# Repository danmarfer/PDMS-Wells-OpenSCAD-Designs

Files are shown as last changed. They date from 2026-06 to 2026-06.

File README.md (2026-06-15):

# PDMS Well Mold Designs — OpenSCAD Parametric Models

Parametric 3D-printable mold designs for casting **PDMS (Polydimethylsiloxane) wells** used in cell biology, microfluidics, and lab-on-a-chip experiments. All files are built in [OpenSCAD](https://openscad.org/) so that any dimension can be changed by editing a single variable — no CAD experience needed.

---

## Who Is This For?

Researchers who need custom PDMS chambers for cell biology, microfluidics, or live-cell imaging experiments, but do not have CAD design experience. All dimensions are exposed as plain variables at the top of each file — adapting a design to your experiment requires no knowledge of 3D modeling.

> A detailed design flow describing the full fabrication workflow is currently under review for publication. This section will be updated with the reference once available.

---

## Repository Contents

| File | Description |
| --- | --- |
| `Well.scad` | The final PDMS well — the part you cast |
| `Lid.scad` | Snap-fit lid with alignment pegs for the well |
| `One part mold.scad` | **(Design A)** Simplest mold — single piece, print-and-use |
| `Removable gate mold.scad` | **(Design B)** Two-part mold with a sliding gate insert |
| `Removable base mold.scad` | **(Design C)** Two-part mold with a removable base peg |
| `Removable cylinder mold.scad` | **(Design D)** Scaled-up two-part mold with a large removable cylinder |

---

## Mold Designs

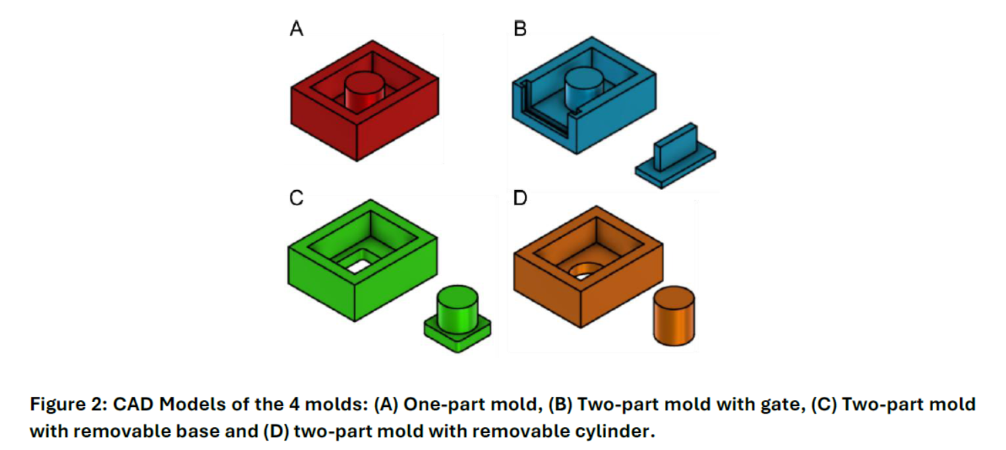
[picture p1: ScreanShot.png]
CAD Models of the 4 molds: (A) One-part mold, (B) Two-part mold with gate, (C) Two-part mold with removable base and (D) two-part mold with removable cylinder.


*Figure: CAD Models of the 4 molds — (A) One-part mold, (B) Two-part mold with gate, (C) Two-part mold with removable base, (D) Two-part mold with removable cylinder.*

---

### A — One-Part Mold (`One part mold.scad`)

The simplest design. The entire mold is a single printed piece. The cylindrical post that forms the well opening is part of the body — nothing to assemble before pouring.

**Default dimensions:**
- Inner cavity: 20 × 15 × 7 mm
- Well hole diameter: 7 mm
- Wall thickness: 2 mm

**Demolding:** Flex the mold walls outward and pull the cured PDMS straight up. Because the cylinder is built-in, this requires more force than the two-part options.

---

### B — Two-Part Mold with Gate (`Removable gate mold.scad`)

The mold body has a slot on one side into which a thin **gate** (a flat sliding insert with a small handle) is inserted after the cylinder is placed. The gate closes the side opening and creates a clean edge on the cured well.

**Default dimensions:**
- Inner cavity: 20 × 15 × 7 mm
- Well hole diameter: 9 mm
- Wall thickness: 2 mm
- Gate handle height: 5 mm

**Assembly:** Place the gate into the slot before pouring PDMS. After curing, remove the gate first, then peel the PDMS well out.

---

### C — Two-Part Mold with Removable Base (`Removable base mold.scad`)

The cylinder that forms the well opening is a separate **peg** that locks into a square socket in the mold floor. 

**Default dimensions:**
- Inner cavity: 20 × 15 × 7 mm
- Well hole diameter: 7.5 mm
- Wall thickness: 3 mm
- Peg-to-socket tolerance: 0.1 mm

**Assembly:** Snap the peg into the floor socket, pour PDMS. After curing, pull the peg out first, then flex the mold walls to release the well.

---

### D — Two-Part Mold with Removable Cylinder (`Removable cylinder mold.scad`)

A scaled-up version where the entire cylindrical insert — rather than just a small peg — is a separate printed piece. The cylinder slides into a hole in the mold floor.

**Default dimensions:**
- Inner cavity: 50 × 40 × 25 mm
- Well hole diameter: 17.5 mm
- Wall thickness: 5 mm
- Cylinder-to-hole tolerance: 0.25 mm

**Assembly:** Insert the cylinder through the floor hole, pour PDMS. After curing, push the cylinder down and out through the floor, then peel out the PDMS well.

---

### Well (`Well.scad`) and Lid (`Lid.scad`)

`Well.scad` is the reference model of the final casted part (20 × 15 × 7 mm, 7 mm hole). Use it for reference or to verify fit before printing a mold.

`Lid.scad` is a snap-on lid for the cured well. It has a 0.5 mm clearance gap around the perimeter and four small alignment pegs on the inner rim that hold it in place on top of the well.

---

## Customizing Dimensions

Each file declares all dimensions as variables at the very top. Open any `.scad` file in a text editor or in OpenSCAD's built-in editor and change the values to fit your experiment:

```openscad
l = 20;         // inner length of the well (mm)
w = 15;         // inner width of the well (mm)
h = 7;          // inner height / depth of the well (mm)
diameter = 7;   // diameter of the well opening (mm)
t = 2;          // mold wall thickness (mm)
tolerance = 0.1; // clearance between interlocking parts (mm)
```

After editing, press **F5** in OpenSCAD to preview or **F6** to do a full render and verify the geometry before exporting.

> **Tip on tolerance:** If the removable peg or cylinder is too tight to insert, increase `tolerance` by 0.05 mm and re-print. If it is too loose, decrease it.

---

## Generating STL Files

Open the `.scad` file in [OpenSCAD](https://openscad.org/downloads.html), render the model, and export it as STL. The STL can then be opened in any slicer (Cura, PrusaSlicer, Bambu Studio) and sent to a 3D printer.

---

## License

These designs are released for free academic and research use. If you use them in a publication, please consider citing this repository.

---

## Contributing

Pull requests are welcome. If you adapt one of these molds for a different well geometry, consider sharing the modified `.scad` file so others can benefit from it.

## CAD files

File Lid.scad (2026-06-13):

l = 20;
w =15;
t = 3;
eps = 0.01;
gap = 0.5;
lt = 1;
pegW = w/25;
lidH = 5;

module lid(){
    translate([0,0,lt/2]) 
        cube([l+gap*2, w+gap*2, lt],center=true);
    
    linear_extrude(lidH)
        difference(){
            square([l+gap*2+lt*2, w+gap*2+lt*2], center=true);
            square([l+gap*2, w+gap*2], center=true);
        }
    
    mirror([1,0,0]) translate([l/2,0,gap/2+lt]) 
        cube([gap*2,pegW,gap], center=true);
        
    translate([l/2,0,gap/2+lt]) 
        cube([gap*2,pegW,gap], center=true);
        
    mirror([0,1,0]) translate([0,w/2,gap/2+lt]) rotate([0,0,90])
        cube([gap*2,pegW,gap], center=true);
        
    translate([0,w/2,gap/2+lt]) rotate([0,0,90])
        cube([gap*2,pegW,gap], center=true);
}

lid();

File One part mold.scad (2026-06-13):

length = 20;
width =15;
height = 7;
diameter = 7;
thickness = 2;
eps = 0.01;
faces = 128;


difference(){
        
    translate([-(length/2 + thickness),-(width/2 + thickness),0]) 
        cube([length+thickness*2, width+thickness*2, height+thickness]);

    translate([-length/2,-width/2,thickness]) 
        cube([length,width,height+eps]);
}


cylinder(height+thickness,d=diameter,$fn=faces);
    

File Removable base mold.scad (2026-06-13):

l = 20;
w =15;
h = 7;
diameter = 7.5;
t = 3; //wall thickness*2
base = 10;
eps = 0.01;
fillet = 0.5;
tolerance = 0.1;
disp = 20;
faces = 128;

module molde(){
    difference(){
        
        translate([-(l/2 + t),-(w/2 + t),0]) 
            cube([l+t*2, w+t*2, h+t]);

        translate([-l/2,-w/2,t]) 
            cube([l,w,h+eps]);
        
        translate([0,0,-eps]) 
            linear_extrude(t+eps*2)
                intersection(){
                    translate([-base/2, -base/2]) 
                        square([base,base]);    
                    translate ([0,0,t/2]) 
                        circle((sqrt(2)*base)/2-fillet, $fn=faces);
                };
    }
};
molde();

module perno(){
 
    linear_extrude(t+eps)
                intersection(){
                    translate([-(base-tolerance)/2, -(base-tolerance)/2]) 
                        square([base-tolerance,base-tolerance]);
                            
                    translate ([0,0,t]) 
                        circle((sqrt(2)*base)/2-fillet-tolerance, $fn=faces);
                };
    translate([0,0,t/2])
                cylinder(h+t/2,d=diameter,$fn=faces);
    
};
color("red") translate([0,disp,0]) perno();

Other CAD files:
Removable cylinder mold.scad
Removable gate mold.scad
Well.scad
